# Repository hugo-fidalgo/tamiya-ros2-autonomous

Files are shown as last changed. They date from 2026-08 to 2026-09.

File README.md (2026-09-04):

<div align="center">
  
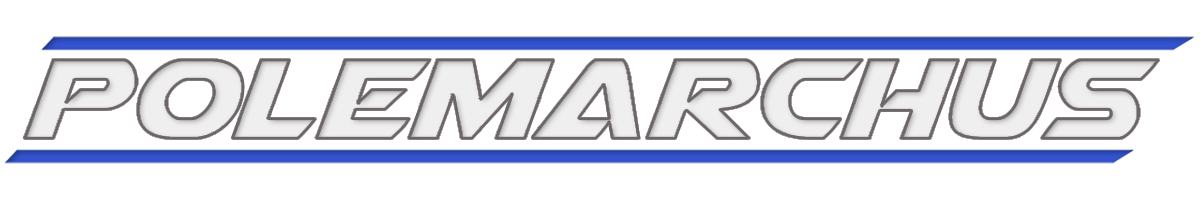
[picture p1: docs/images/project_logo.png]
  

  **A 1:10 scale ROS 2 Teleoperated Perception Ground Vehicle**
  
  
  
  
  
</div>

## System Overview
Polemarchus is a 1:10 scale robotics platform based on the Tamiya TT-02 chassis (A popular introductory Kit Car). The current iteration features a fully verified ROS 2 teleoperation and LiDAR Perception stack in real time over WI-FI. In this repository you will find all the files used for this initial prototype (Firmware; Hardware: Mechanical, Electronics; ROS 2 Software; Docker). 

<div align="center">

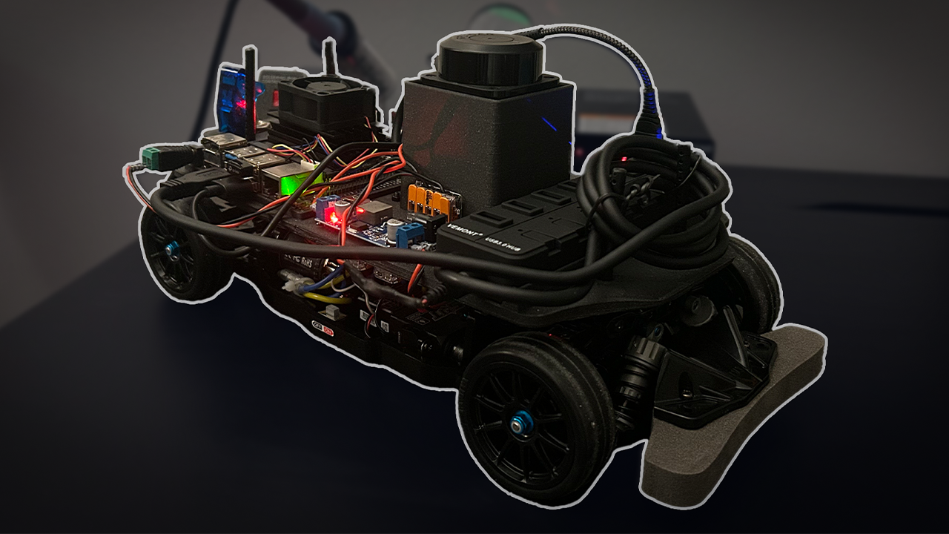
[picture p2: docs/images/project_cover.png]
Project Demonstration (https://youtu.be/ehe3ica5O2w)
  

  *Click the image above to view the physical system demo.*

</div>

- [System Overview](#system-overview)
- [Mechanical Architecture](#mechanical-architecture)
- [Electrical Architecture](#electrical-architecture)
- [Software Architecture](#software-architecture)
- [Quick Start & Simulation](#quick-start--simulation)
- [Future Roadmap](#future-roadmap)

## Mechanical Architecture
The physical platform utilizes an RC racing chassis, with a 3D printed custom designed deck that holds all electronic components and wiring.

* **Chassis:** Tamiya TT-02R
* **Vetronics Deck [SolidWorks Files]:** `hardware/mechanical/solidworks`

<div align="center">

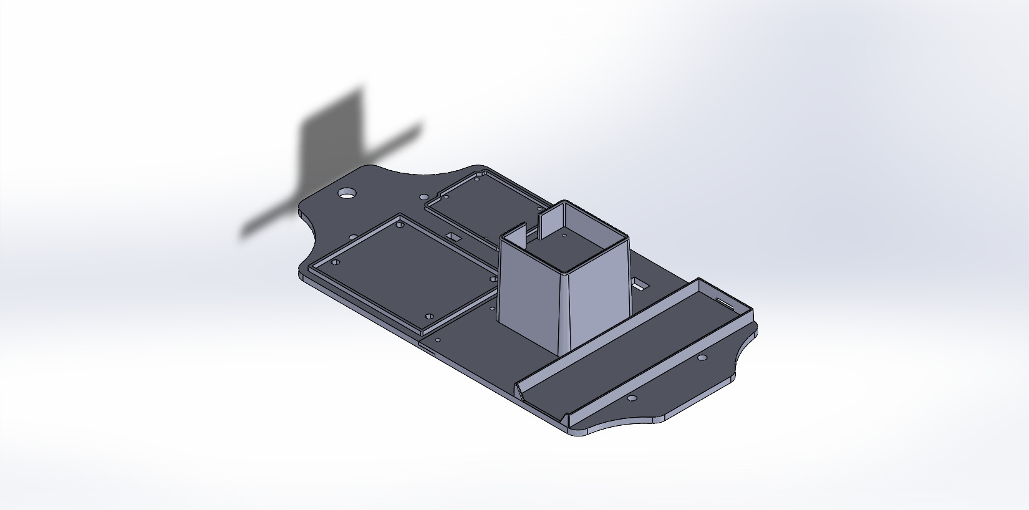
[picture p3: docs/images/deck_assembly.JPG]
Vetronics Deck
  

</div>

* **Robot Description:** Full URDF/Xacro representation for simulation purposes. `src/tamiya_rover_description/description`

## Electrical Architecture
This rover utilizes an On-Board computer, running a custom docker container, which communicates over serial with the MicroController Unit.

* **OBC:** Jetson Nano DevKit (2019)
* **MCU:** Arduino Uno R4 WIFI

Below you can find a simplified electronics diagram of the rover's EPS, OBDH and GNC subsystems. It can also be found here: `hardware/schematics/vetronics/vetronics.kicad_sch`

<div align="center">

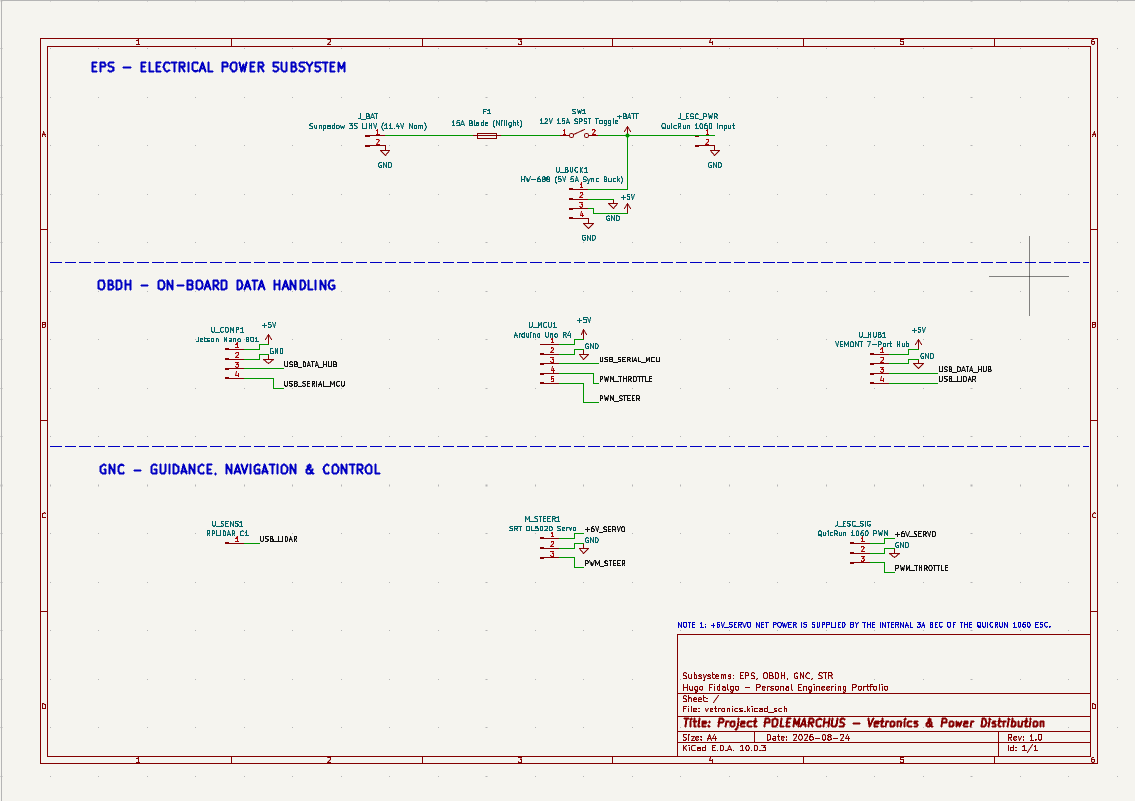
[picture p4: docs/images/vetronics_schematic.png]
Electronics Schematic
  

</div>

There is also a bill of materials of the components used. `hardware/bom/ROS-2_Tamiya_TT-02R_[BOM].xlsx`

The Arduino Uno R4 controls the vehicle's actuators. Developed in C++ via PlatformIO.

* **Serial Ingestion:** Continuously reads and parses comma-separated strings from the Jetson Nano (OBC).

* **PWM translation:** Converts digital commands into microsecond PWM signals to control the Electronic Speed Controller (ESC) and steering servo.

* **Embedded Failsafes:** Integrates a watchdog timer to halt the car in case no commands were sent for more than 500ms.

All logic is documented inline within: `firmware/mcu_firmware/src/main.cpp`

## Software Architecture
The software stack is built entirely on ROS 2 Humble.

* **Control:** Custom ROS 2 Node that subscribes to the `/cmd_vel` topic and sends the correct PWM Signal in microseconds to the MCU. `src/rover_mcu_bridge/src/mcu_bridge_node.cpp`

* **Gazebo Simulation:** Physics simulation using Gazebo which bridges the ROS 2 topics through `ros_gz_bridge`. All programs are initialized by an automated sim.launch.py script. `src/tamiya_rover_description/launch/sim.launch.py`

* **Perception:** Native integration of the RPLIDAR C1 node publishing LaserScan data to RViz.

## Quick Start & Simulation

**Prerequisites:**

* **Linux/macOS:** Ensure Docker and Docker Compose are installed.
* **Windows:** You must have Docker Desktop installed with the WSL2 backend enabled. All .sh scripts must be executed from within a WSL2 terminal (e.g, Ubuntu 22.04 on WSL) to support graphical forwarding for RViz and Gazebo.

**Simulation Setup:**

**Clone the repository:**
```
git clone https://github.com/hugo-fidalgo/tamiya-ros2-autonomous.git
cd tamiya-ros2-autonomous
```

**Build and launch the containerized environment:**
```
chmod +x run_desktop.sh
./run_desktop.sh

cd ~/dev_ws
colcon build --symlink-install
source install/setup.bash
```

**Launch the simulation:**

This script should launch both RViz and Gazebo.

```
ros2 launch tamiya_rover_description sim.launch.py
```
<div align="center">

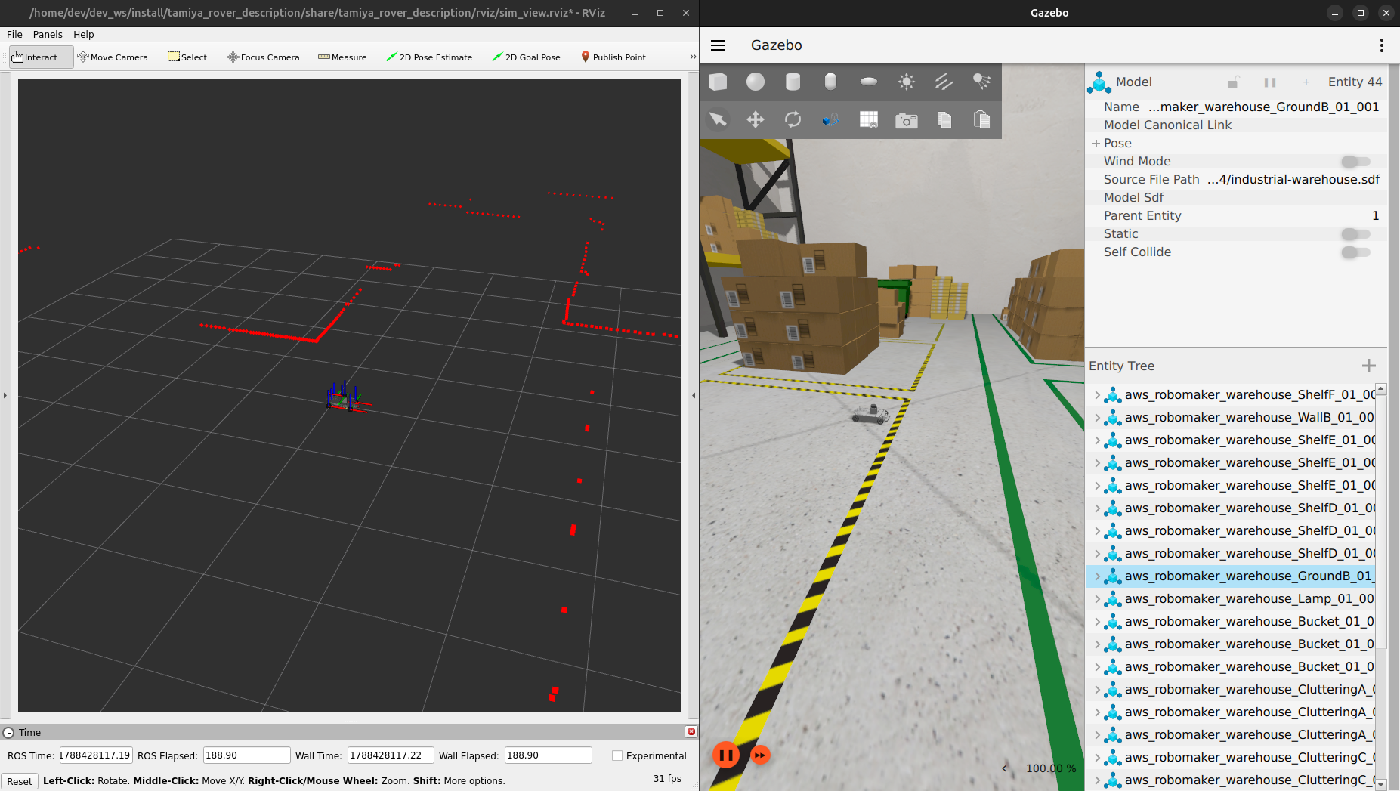
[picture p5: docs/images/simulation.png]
Gazebo and RViz Visualization


</div>

**Control the  simulated car:**
Open another terminal, here you will send `/cmd_vel` commands with your keyboard.

```
docker exec -it sim-environment bash
ros2 run teleop_twist_keyboard teleop_twist_keyboard
```

**Physical Car Setup:**

Both the physical car and your laptop must be connected to the same Wi-Fi network.

Connect to the car using ssh.

You should have two terminals, one for the car (connected over ssh) and one for the laptop.

**On the car's terminal:**

**Clone the repository:**
```
git clone https://github.com/hugo-fidalgo/tamiya-ros2-autonomous.git
cd tamiya-ros2-autonomous
```

**Build and launch the containerized environment:**
```
chmod +x run_jetson.sh
./run_jetson.sh

cd ~/robot_ws
colcon build --symlink-install
source install/setup.bash
```

**Launch the hardware script:**
```
ros2 launch tamiya_rover_description hardware.launch.py
```

**On the laptop's terminal:**

**Clone the repository:**
```
git clone https://github.com/hugo-fidalgo/tamiya-ros2-autonomous.git
cd tamiya-ros2-autonomous
```

**Build and launch the containerized environment:**
```
chmod +x run_desktop.sh
./run_desktop.sh

cd ~/dev_ws
colcon build --symlink-install
source install/setup.bash
```

**Control the  physical car:**
Open another terminal, here you will send `/cmd_vel` commands with your keyboard.

```
docker exec -it sim-environment bash
ros2 run teleop_twist_keyboard teleop_twist_keyboard
```

**Visualize the car perception sensors:**
Open another terminal, here you will initialize RViz to visualize the car LaserScan.

```
docker exec -it sim-environment bash
rviz2 -d src/tamiya_rover_description/rviz/robot_view.rviz
```

## Future Roadmap

Here I lay out fixes and future implementations needed for this project to reach the goal of becoming fully autonomous.

**Fix:**
* **Vetronics Deck Redesign:** The Vetronics Deck must be redesigned to accommodate a camera and possibly a depth camera, also a specific physical layer for wiring and electrical logic should be added so it's easier to assemble and debug the car.

**Implementations:**
* **Cameras:** Implement both a camera and a depth camera to the car.
* **SLAM:** Implement slam_toolbox (ROS 2).   
* **Navigation:** Implement ROS 2 NAV 2.

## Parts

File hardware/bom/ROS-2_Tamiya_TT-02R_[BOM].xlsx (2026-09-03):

Item ID | Subsystem | Component Name | Manufacturer / Part Number | Supplier | Qty | Unit Cost (DKK) | Key Parameters / Specs | Datasheet Link | Store Link
STR-01 | STR | 1/10 TT-02R Chassis Kit | Tamiya (TAM58663) | RC Kongen | 1 | 1099 | 4WD Shaft-driven, Standard 540 mount | Tamiya Manual PDF (https://www.tamiya.com/cms/english/rc/rcmanual/84409.pdf) | RC Kongen Link (https://www.rckongen.dk/)
OBDH-01 | OBDH | NVIDIA Jetson Nano Developer Kit (4GB, B01) | NVIDIA (945-13450-0000-100) | Used (Secondary Market) | 1 | 726 | Quad-core ARM Cortex-A57 @ 1.43 GHz, 128-core Maxwell GPU, 4GB LPDDR4 | NVIDIA Jetson Docs (https://developer.download.nvidia.com/assets/embedded/secure/jetson/Nano/docs/NVIDIA_Jetson_Nano_Developer_Kit_User_Guide.pdf) | DBA (https://www.dba.dk/)
GNC-01 | GNC | RPLIDAR C1M1 DTOF Sensor | Slamtec (C1M1) | Amazon.de | 1 | 618 | 12m Range, DTOF, USB interface | Slamtec C1 Datasheet (https://download.kamami.pl/p1188506-SLAMTEC_rplidar_datasheet_C1_v1.0_en.pdf) | Amazon.de Link
GNC-02 | GNC | SRT DL5020 Digital Servo | SRT (DL5020) | RC Kongen | 1 | 299 | 20 kg-cm @ 6V, Metal Gear, Waterproof | SRT Manual (https://www.srt-rc.com/data/upload/file/202105/28d58f5e852d3c00508e5f0fdde96137.pdf) | RC Kongen Link (https://www.rckongen.dk/)
EPS-01 | EPS | 11.4V 3S 3700mAh 100C LiHV | Sunpadow (SW281570) | RC Kongen | 1 | 269 | 11.4V Nom / 13.05V Max, T-Plug, XH Balance | RC Kongen Product Specs (https://rckongen.dk/products/li-po-battery-3s-11-4v-3700mah-100c-hv-t-connector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) | RC Kongen Link (https://www.rckongen.dk/)
EPS-02 | EPS | QuicRun 1060 Brushed ESC | Hobbywing (30120020) | RC Kongen | 1 | 199 | 60A Cont / 360A Peak, 2-3S LiPo, 6V/3A BEC | Hobbywing Manual (https://www.hobbywing.com/en/uploads/file/20240315/4806bbdbab8eb9fea0bb26da87d81b00.pdf) | RC Kongen Link (https://www.rckongen.dk/)
OBDH-02 | OBDH | VEMONT 7-Port Powered USB Hub | VEMONT (7-Port + 5V3A) | Amazon.de | 1 | 193.54 | USB 3.0, External DC 5V barrel input | Amazon.de Product Specs (https://www.amazon.de/-/da/3-0-hub-str%C3%B8madapter-VEMONT-USB-hub-5V3A-adapter-Sort-7-porte-5V3A/dp/B01N631DZ9) | Amazon.de Link
OBDH-03 | OBDH | Arduino UNO R4 WiFi | Arduino (ABX00087) | Used (Secondary Market) | 1 | 182.41 | Renesas RA4M1 (Cortex-M4) 48MHz, ESP32-S3 WiFi/BT, 5V Logic | Arduino R4 Docs (https://docs.arduino.cc/resources/datasheets/ABX00087-datasheet.pdf) | DBA (https://www.dba.dk/)
GNC-03 | GNC | QuicRun 540-40T Brushed Motor | Hobbywing (30403153) | RC Kongen | 1 | 149 | 40T, 10,500 RPM @ 7.4V, Max 12.6V | Hobbywing Spec Sheet (https://www.hobbywing.com/en/products/quicrunbrushed540555) | RC Kongen Link (https://www.rckongen.dk/)
EPS-03 | EPS | ABSIMA LC-2.0 AC Charger | ABSIMA (4000034) | RC Kongen | 1 | 129 | 25W, Supports LiHV & Storage Mode | RC Kongen Product Specs (https://rckongen.dk/products/absima-4000034?variant=52655077294416) | RC Kongen Link (https://www.rckongen.dk/)
EPS-04 | EPS | VISSQH 12V 15A Toggle Switch | VISSQH (12V Toggle) | Amazon.de | 1 | 78.42 | SPST Heavy Duty Metal Switch | Amazon.de Product Specs (https://www.amazon.de/dp/B08G4R8D3K?ref=ppx_yo2ov_dt_b_fed_asin_title&th=1) | Amazon.de Link
EPS-05 | EPS | Nilight Inline Fuse Holder + 15A | Nilight (NI-FH01) | Amazon.de | 1 | 66.61 | 14 AWG Wire, Standard ATC/ATO | Amazon.de Product Specs (https://www.amazon.de/dp/B07426WCLM?ref=ppx_yo2ov_dt_b_fed_asin_title&th=1) | Amazon.de Link
EPS-06 | EPS | HW-688 5V 5A Step-Down Buck | Generic / Fastpaw (HW-688) | Amazon.de | 3 | 62.72 | Input 9V-24V, Output 5V/5A, Synch Rectifier | Amazon.de Product Specs (https://www.amazon.de/dp/B0GKY19J9Q?ref=ppx_yo2ov_dt_b_fed_asin_title&th=1) | Amazon.de Link
EPS-07 | EPS | Vapex LiPo Safe Bag | Vapex (VPLIPOBAGD) | RC Kongen | 1 | 45 | 125x64x50mm Fireproof Fabric | RC Kongen Product Specs (https://rckongen.dk/products/safebag-til-lipo-batterier?variant=52597739454800) | RC Kongen Link (https://www.rckongen.dk/)

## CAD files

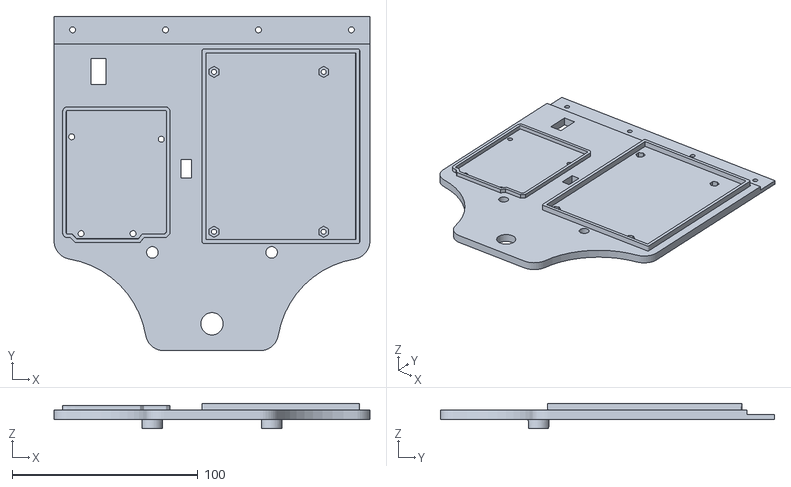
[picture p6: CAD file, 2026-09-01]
hardware/mechanical/manufacturing/deck_rear.STL
170.0 x 179.9 x 13.5

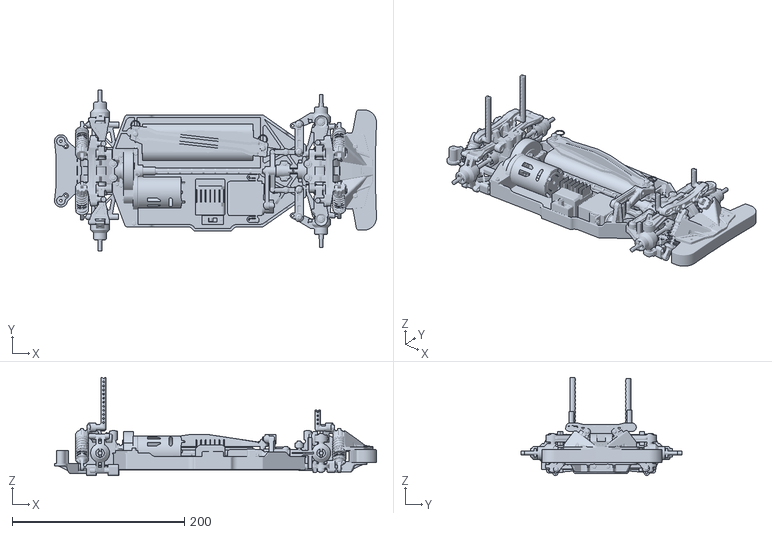
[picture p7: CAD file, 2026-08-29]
src/tamiya_rover_description/meshes/tt02d_chassis.stl
374.3 x 187.0 x 114.2

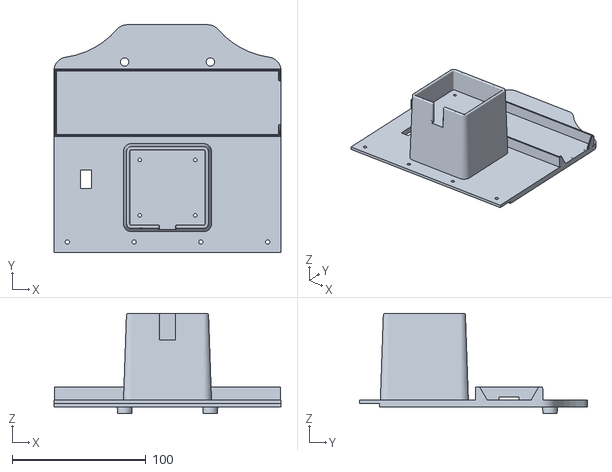
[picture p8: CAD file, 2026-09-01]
hardware/mechanical/manufacturing/deck_front.STL
170.0 x 170.4 x 75.0

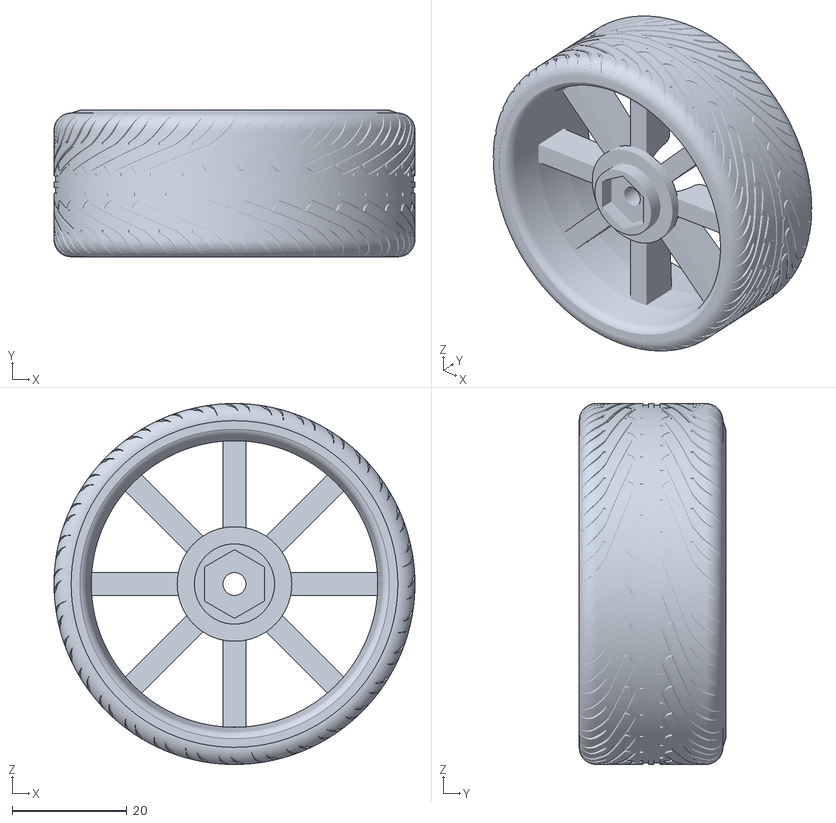
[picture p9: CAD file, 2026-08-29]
src/tamiya_rover_description/meshes/tt02d_wheel.stl
63.0 x 25.6 x 63.0

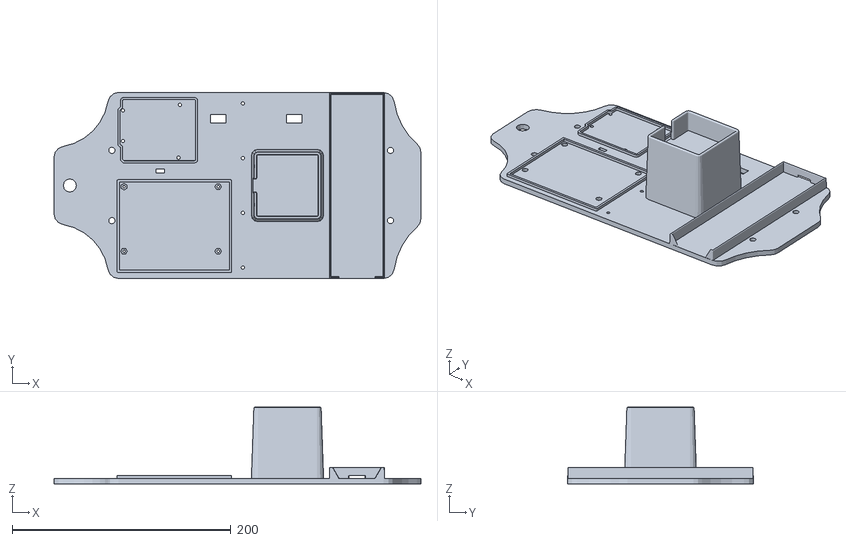
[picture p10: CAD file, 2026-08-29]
src/tamiya_rover_description/meshes/vetronics_deck.stl
335.4 x 170.0 x 70.0

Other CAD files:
hardware/mechanical/solidworks/deck_assembly.SLDASM
hardware/mechanical/solidworks/deck_rear.SLDPRT
hardware/mechanical/solidworks/deck_front.SLDPRT

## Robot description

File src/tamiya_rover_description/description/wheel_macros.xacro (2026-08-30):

<?xml version="1.0"?>
<robot xmlns:xacro="http://www.ros.org/wiki/xacro">

    <!-- Fixed Wheel Macro -->
    <xacro:macro name="fixed_wheel" params="prefix x_offset y_reflect">
        <joint name="${prefix}_wheel_joint" type="continuous">
            <parent link="base_link"/>
            <child link="${prefix}_wheel_link"/>
            <origin xyz="${x_offset} ${y_reflect * wheel_offset_y} ${wheel_offset_z}" rpy="0 0 0"/>
            <axis xyz="0 1 0"/>
        </joint>
    

        <link name="${prefix}_wheel_link">
            <visual>
                <geometry>
                    <mesh filename="package://tamiya_rover_description/meshes/tt02d_wheel.stl" scale="0.001 0.001 0.001"/>
                </geometry>
                <!-- Dinamically flip the mesh -->
                <origin xyz="0 0 0" rpy="0 0 ${(1 - y_reflect) / 2 * pi}"/>
                <material name="black"/>
            </visual>
            <collision>
                <geometry>
                    <cylinder radius="${wheel_radius}" length="${wheel_length}"/>
                </geometry>
                <origin xyz="0 0 0" rpy="-${pi / 2} 0 0"/>
                <material name="black"/>
            </collision>
            <xacro:inertial_cylinder mass="${wheel_mass}" length="${wheel_length}" radius="${wheel_radius}">
                <origin xyz="0 0 0"/>
            </xacro:inertial_cylinder>
        </link>

        <!-- Tire Friction -->
        <gazebo reference="${prefix}_wheel_link">
            <mu1>0.9</mu1>
            <mu2>0.9</mu2>
            <kp>100000000.0</kp>
            <kd>1.0</kd>
        </gazebo>

    </xacro:macro>

    <!-- Steered Wheel Macro -->
     <xacro:macro name="steered_wheel" params="prefix x_offset y_reflect">
        <!-- Steering Knuckle -->
        <joint name="${prefix}_steer_joint" type="revolute">
            <parent link="base_link"/>
            <child link="${prefix}_steer_link"/>
            <origin xyz="${x_offset} ${y_reflect * wheel_offset_y} ${wheel_offset_z}"/>
            <axis xyz="0 0 1"/>
            <limit lower="-${max_steer_angle}" upper="${max_steer_angle}" effort="10.0" velocity="5.0"/>
        </joint>

        <!-- Steering Knuckle Inertial Tag for simulation -->
        <link name="${prefix}_steer_link">
            <xacro:inertial_box mass="0.01" x="0.02" y="0.02" z="0.02">
                <origin xyz="0 0 0"/>
            </xacro:inertial_box>
        </link>

        <!-- Wheel -->
        <joint name="${prefix}_wheel_joint" type="continuous">
            <parent link="${prefix}_steer_link"/>
            <child link="${prefix}_wheel_link"/>
            <origin xyz="0 0 0" rpy="0 0 0"/>
            <axis xyz="0 1 0"/>
        </joint>

        <link name="${prefix}_wheel_link">
            <visual>
                <geometry>
                    <mesh filename="package://tamiya_rover_description/meshes/tt02d_wheel.stl" scale="0.001 0.001 0.001"/>
                </geometry>
                <!-- Dinamically flip the mesh -->
                <origin xyz="0 0 0" rpy="0 0 ${(1 - y_reflect) / 2 * pi}"/>
                <material name="black"/>
            </visual>
            <collision>
                <geometry>
                    <cylinder radius="${wheel_radius}" length="${wheel_length}"/>
                </geometry>
                <origin xyz="0 0 0" rpy="-${pi / 2} 0 0"/>
            </collision>
            <xacro:inertial_cylinder mass="${wheel_mass}" length="${wheel_length}" radius="${wheel_radius}">
                <origin xyz="0 0 0"/>
            </xacro:inertial_cylinder>
        </link>

        <gazebo reference="${prefix}_wheel_link">
            <mu1>0.9</mu1>
            <mu2>0.9</mu2>
            <kp>100000000.0</kp>
            <kd>1.0</kd>
        </gazebo>
        
     </xacro:macro>
</robot>

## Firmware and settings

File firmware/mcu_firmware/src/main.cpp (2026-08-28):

#include <Arduino.h>
#include <Servo.h>

// Define hardware pins for the Tamiya chassis actuators
const int THROTTLE_PIN = 9; // Connects to the ESC signal wire
const int STEERING_PIN = 10; // Connects to the Steering Servo signal wire

Servo escServo;
Servo steeringServo;

// String buffer to accumulate incoming serial bytes
String inputString = "";
bool stringComplete = false;

// Safety timeout tracking variables
unsigned long lastPacketTime = 0;
const unsigned long SAFETY_TIMEOUT_MS = 500; // Stop the rover if no packe is received for 0.5 seconds

void setup() 
{
  // Initialize USB serial communications at 115200 baud matching Jetson Nano
  Serial.begin(115200);
  inputString.reserve(50); // Allocate memory for the incoming string
  
  // Attach servo objects to their respective microcontroller pins
  escServo.attach(THROTTLE_PIN);
  steeringServo.attach(STEERING_PIN);

  // Initialize both to neutral on boot
  escServo.writeMicroseconds(1500);
  steeringServo.writeMicroseconds(1500);
}

void loop() 
{
  // Non-Blocking Serial Ingestion 
  while (Serial.available() > 0) 
  {
    char inChar = (char)Serial.read();

    if (inChar == '\n')
    {
      stringComplete = true; // Flag that a full packet arrived
      break;
    }
    else if (inChar != '\r')
    {
      inputString += inChar; // Accumulate characters in the buffer
    }
  }

  // Process Packed When Complete
  if (stringComplete)
  {
    // Find the position of the comma separator
    int commaIndex = inputString.indexOf(',');

    if (commaIndex > 0)
    {
      // Extract throttle and steering substrings and convert to integers
      String throttleStr = inputString.substring(0, commaIndex);
      String steeringStr = inputString.substring(commaIndex + 1);

      int throttleVal = throttleStr.toInt();
      int steeringVal = steeringStr.toInt();

      // Enforce safety limits
      throttleVal = constrain(throttleVal, 1000, 2000);
      steeringVal = constrain(steeringVal, 1000, 2000);

      // Write values out to the hardware
      escServo.writeMicroseconds(throttleVal);
      steeringServo.writeMicroseconds(steeringVal);

      // Reset safety timer 
      lastPacketTime = millis();
    }

    // Reset string buffeer for the next loop
    inputString = "";
    stringComplete = false;

  }

  // Safety Timout Check
    if (millis() - lastPacketTime > SAFETY_TIMEOUT_MS) 
    {
      escServo.writeMicroseconds(1500);
      steeringServo.writeMicroseconds(1500);
    }
}

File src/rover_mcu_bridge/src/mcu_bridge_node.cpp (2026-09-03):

#include "rclcpp/rclcpp.hpp"
#include "geometry_msgs/msg/twist.hpp"
#include <sstream>
#include <fcntl.h>
#include <errno.h>
#include <termios.h>
#include <unistd.h>

class McuBridgeNode : public rclcpp::Node 
{
    public:
        // Constructor
        McuBridgeNode() : Node("mcu_bridge") 
        {
            // Initialize the subscriber
            subscription_ = this->create_subscription<geometry_msgs::msg::Twist>(
                "cmd_vel", 10, std::bind(&McuBridgeNode::cmd_vel_callback, this, std::placeholders::_1));

            RCLCPP_INFO(this->get_logger(), "MCU Bridge Initialized. Listening to /cmd_vel...");

            serial_fd_ = open("/dev/arduino_mcu", O_RDWR | O_NOCTTY | O_NDELAY);

            if (serial_fd_ < 0) 
            {
                RCLCPP_ERROR(this->get_logger(), "Failed to open serial port /dev/arduino_mcu! Error: %s", strerror(errno));
            }
            else
            {
                RCLCPP_INFO(this->get_logger(), "Successfully opened serial port /dev/arduino_mcu.");

                // Configure Serial Port Parameters
                configure_serial_port();
            }
        }

        // Destructor 
        ~McuBridgeNode() 
        {
            if (serial_fd_ >= 0)
            {
                close(serial_fd_);
                RCLCPP_INFO(this->get_logger(), "Closed serial port /dev/arduino_mcu.");
            }
        }

    private:
        void configure_serial_port() 
        {
            struct termios tty;

            // Read current serial attributes
            if (tcgetattr(serial_fd_, &tty) != 0)
            {
                RCLCPP_ERROR(this->get_logger(), "Error from tcgetattr: %s", strerror(errno));
                return;
            }

            // Set Baud Rate to 115200
            cfsetospeed(&tty, B115200);
            cfsetispeed(&tty, B115200);

            // Control modes (8N1 standard)
            tty.c_cflag &= ~PARENB; // Clear parity bit (no parity)
            tty.c_cflag &= ~CSTOPB; // Clear stop field (1 stop bit)
            tty.c_cflag &= ~CSIZE; // Clear size bits
            tty.c_cflag |= CS8; // Set 8 data bits

            tty.c_cflag &= ~CRTSCTS; // Disable hardware flow control (RTS/CTS)
            tty.c_cflag |= CREAD | CLOCAL; // Turn on Read & ignore control lines (Local line)

            // Raw input/output processinhg mode (disables cannonical terminal translation)
            tty.c_lflag &= ~ICANON;
            tty.c_lflag &= ~ECHO;
            tty.c_lflag &= ~ECHOE;
            tty.c_lflag &= ~ISIG;

            tty.c_iflag &= ~(IXON | IXOFF | IXANY); // Disable software flow control
            tty.c_iflag &= ~(IGNBRK|BRKINT|PARMRK|ISTRIP|INLCR|IGNCR|ICRNL); // Disable special handling of input bytes

            tty.c_oflag &= ~OPOST;
            tty.c_oflag &= ~ONLCR;

            // Apply the configured settings
            if (tcsetattr(serial_fd_, TCSANOW, &tty) != 0) 
            {
                RCLCPP_ERROR(this->get_logger(), "Error from tcsetattr: %s", strerror(errno));
            }
        }
        
        void cmd_vel_callback(const geometry_msgs::msg::Twist::SharedPtr msg) const 
        {
            double linear_v = msg->linear.x; // Forward/Reverse velocity (m/s)
            double angular_w = msg->angular.z * -1.0; // Steering rotation (rad/s)

            // Calibration Constants
            const double MAX_INPUT_LINEAR_VEL = 4.0; // m/s 
            const double MAX_INPUT_ANGULAR_VEL = 1.0; // rad/s
            const int PWM_CENTER = 1500; // us
            const int PWM_MAX_DEVIATION = 500; // Maximum offset from center (1000 to 2000 us) 

            // Map linear velocity (-2.0 to 2.0 m/s assumed max) to PWM (1000 to 2000 us, 1500 is neutral)
            // Using a simple linear scaling factor:
            double linear_scale = PWM_MAX_DEVIATION / MAX_INPUT_LINEAR_VEL;
            int throttle_pwm = static_cast<int>(PWM_CENTER + (linear_v * linear_scale));

            // Map angular velocity to steering servo PWM (1000 to 2000 us, 1500 is center)
            double angular_scale = PWM_MAX_DEVIATION / MAX_INPUT_ANGULAR_VEL;
            int steering_pwm = static_cast<int>(PWM_CENTER + (angular_w * angular_scale));

            // Safety Limits 
            throttle_pwm = std::clamp(throttle_pwm, 1000, 2000);
            steering_pwm = std::clamp(steering_pwm, 1000, 2000);

            // Format into a string buffer
            std::ostringstream oss;
            oss << throttle_pwm << "," << steering_pwm << "\n";
            std::string serial_packet = oss.str();

            // Write bytes directly to the Linux file descriptor
            write(serial_fd_, serial_packet.c_str(), serial_packet.length());

            // Log the output
            RCLCPP_INFO(this->get_logger(), "Packet Out -> %s", serial_packet.c_str());


        }

        // Private member variables
        int serial_fd_;
        rclcpp::Subscription<geometry_msgs::msg::Twist>::SharedPtr subscription_;
};

int main(int argc, char * argv[])
{
    rclcpp::init(argc, argv);
    rclcpp::spin(std::make_shared<McuBridgeNode>());
    rclcpp::shutdown();
    return 0;
}

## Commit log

2026-08-17 feat: created a multi-stage docker container for development
2026-08-17 feat: created the core urdf
    [inertial_macros.xacro, robot.urdf.xacro, robot_core.xacro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]
2026-08-24 hardware: complete vetronics schematic layout
    [vetronics.kicad_pcb, vetronics.kicad_sch]
2026-08-26 feat(sim): add initial Gazebo simulation definitions
    [gazebo_control.xacro, robot.urdf.xacro, robot_core.xacro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]
2026-08-28 feat(system): integrate micro-controller firmware bridge for the car actuators
    [gazebo_control.xacro, inertial_macros.xacro, robot.urdf.xacro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]
2026-08-29 hardware: added mechanical components
    hw(vetronics): fixed electronic inconsistency with the rplidar in the schematic
    [BasePlate_front.SLDPRT, BasePlate_rear.SLDPRT, baseplate_front.STL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]
2026-08-29 feat(simulation): added meshes files for visualization
    [tt02d_chassis.stl, tt02d_wheel.stl, vetronics_deck.stl]
2026-08-29 hw(fix): added the missing hole for the cable of the lidar
    [BasePlate_front.SLDPRT, baseplate_front.STL, baseplate_rear.STL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]
2026-08-29 hw(fix): fixed coordinate system origins of the stl meshes
    [deck_assembly.SLDASM, tt02d_chassis.stl, tt02d_wheel.stl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]
2026-08-29 hw(fix): added m2.5 hole for the lidar base
    [deck_assembly.SLDASM, deck_front-1.STL, deck_front.SLDPRT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]
2026-08-29 fix(simulation): fixed the coordinate origin of the meshes
    [tt02d_chassis.stl, tt02d_wheel.stl, vetronics_deck.stl]
2026-08-29 feat(sim): added visual meshes and automated ROS 2 Gazebo bridge
    [robot_core.xacro, robot_materials.xacro, wheel_macros.xacro]
2026-08-30 feat: Integrated rplidar
    [lidar.xacro, robot.urdf.xacro, robot_materials.xacro]
2026-08-30 feat: added launch script for on-board-computer
2026-08-30 fix: added executable permission to the jetson initialization script
2026-08-30 fix: fixxed typo on jetson initialization script
2026-08-30 fix: fixed jetson initialization script typos
2026-08-30 feat: completed obc stage for the robot docker image
2026-08-30 fix: fixed type on jetson initialization script
2026-08-30 feat: implemented autostart script for the jetson system service
2026-08-30 fix: made meshes paths relative to the package for visualization over ssh
    [robot_core.xacro, wheel_macros.xacro]
2026-09-01 fix(hw): fixed rp lidar screws centering
    [deck_assembly.SLDASM, deck_front.SLDPRT, deck_front.STL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]
2026-09-02 fix: calibrated speed and turning values and fixed steering direction
    [mcu_bridge_node.cpp]
2026-09-02 fix: further calibrated the linear velocity
    [mcu_bridge_node.cpp]
2026-09-02 fix: fixed lidar orientation in robot_description
    [lidar.xacro]
2026-09-03 docs: initial read.me draft
    [ROS-2_Tamiya_TT-02R_[BOM].xlsx]
2026-09-04 docs: final readme.md draft of the first prototype
